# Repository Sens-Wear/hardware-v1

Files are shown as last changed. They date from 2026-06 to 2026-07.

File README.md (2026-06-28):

# SensWear Hardware

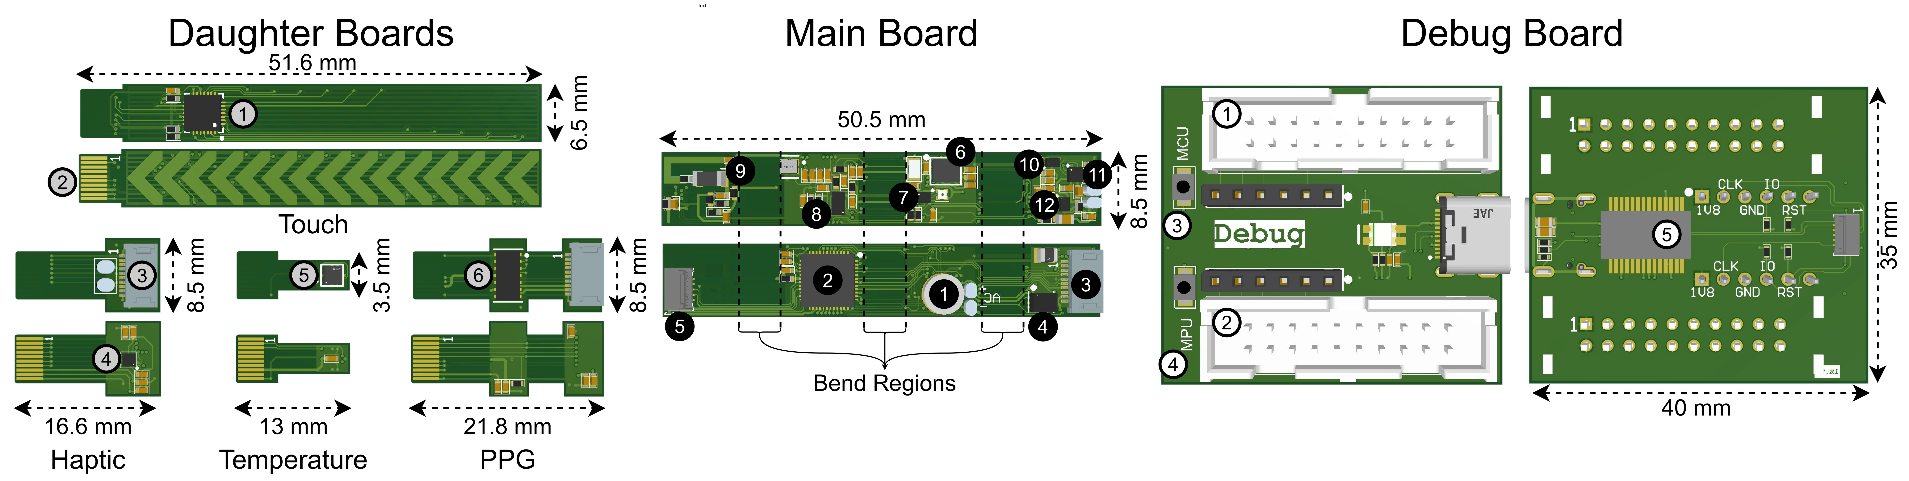
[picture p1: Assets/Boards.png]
SensWear hardware boards


SensWear is a modular wearable sensing platform. This repository contains the Altium Designer source files, reusable component libraries, PCB layouts, schematics, generated documentation, and manufacturing outputs for the SensWear V1R1 hardware.

The design is split into a main board and several function-specific boards so that each part of the system can be developed, reviewed, manufactured, and tested independently. A multi-board project is also included to support system-level integration.

## Repository structure

```text
hardware-v1/
├── Assets/                       Shared project assets
├── Components/                   Reusable schematic and PCB component libraries
│   └── IBIS/                     Signal-integrity models
├── Resources/                    Supporting design resources
├── Templates/                    Altium document and project templates
├── SensWear-V1R1-Main/           Main controller/hub board
├── SensWear-V1R1-Debug/          Programming, debug, SWD, and UART-to-USB board
├── SensWear-V1R1-Haptic/         Haptic-feedback board
├── SensWear-V1R1-PPG/            Optical PPG sensing board
├── SensWear-V1R1-Temperature/    Temperature-sensing board
├── SensWear-V1R1-Touch/          Touch-sensing board
├── SensWear-V1R1-Panel/          Sensor-panel PCB and panel manufacturing project
├── SensWear_V1R1/                Altium multi-board integration project
└── SensWear_V1R1.DsnWrk          Top-level Altium design workspace
```

Most board folders follow this layout:

```text
SensWear-V1R1-<Board>/
├── *.PrjPcb                      Altium PCB project
├── Schematics/ or Schematic/     Schematic source documents
├── PCB/                          PCB layout source document
├── Output/                       Generated review and manufacturing files
│   └── Manufacturing/
│       ├── Assembly/             BOM, pick-and-place, and assembly drawings
│       └── Fabrication/          Gerber and NC drill files
├── Project Outputs for .../      Altium-generated reports and validation results
└── History/                      Local Altium document history, where present
```

The Altium source files are the authoritative design sources. Files under `Output/` and `Project Outputs for .../` are generated artifacts and may need to be regenerated after a source change.

## Board documentation and generated outputs

The following links point to the primary generated documents for each hardware section. The `Manufacturing` links provide access to the available BOMs, pick-and-place files, assembly drawings, Gerbers, drill files, and packaged fabrication outputs.

| Section | Purpose | Design documentation | Manufacturing documentation and outputs |
|---|---|---|---|
| Main board | Central hub containing the main processing, power, memory, and system interfaces | [Schematics PDF](SensWear-V1R1-Main/Output/SensWear_V1R1_Schematics.PDF) | [Manufacturing PDF](SensWear-V1R1-Main/Output/Manufacturing/Assembly/SensWear_MainBoard_Manufacturing.PDF) · [All manufacturing outputs](SensWear-V1R1-Main/Output/Manufacturing/) |
| Debug board | Programming and debugging interfaces, including SWD and UART-to-USB | [Documentation PDF](SensWear-V1R1-Debug/Output/SensWear_Debug_Documentation.PDF) · [Schematics PDF](SensWear-V1R1-Debug/Output/SensWear_Debug_Schematics.PDF) | [Manufacturing PDF](SensWear-V1R1-Debug/Output/Manufacturing/Assembly/SensWear_Debug_Manufacturing.PDF) · [All manufacturing outputs](SensWear-V1R1-Debug/Output/Manufacturing/) |
| Haptic board | Haptic-feedback circuitry | [Documentation PDF](SensWear-V1R1-Haptic/Output/SensWear_Haptic_Documentation.PDF) | No standalone manufacturing PDF is currently included · [All manufacturing outputs](SensWear-V1R1-Haptic/Output/Manufacturing/) |
| PPG board | Optical photoplethysmography sensing | [Documentation PDF](SensWear-V1R1-PPG/Output/SensWear_PPG_Documentation.PDF) | [Manufacturing PDF](SensWear-V1R1-PPG/Output/Manufacturing/Assembly/SensWear_PPG_Manufacturing.PDF) · [All manufacturing outputs](SensWear-V1R1-PPG/Output/Manufacturing/) |
| Temperature board | Temperature sensing | [Documentation PDF](SensWear-V1R1-Temperature/Output/SensWear_Temperature_Documentation.PDF) | [Manufacturing PDF](SensWear-V1R1-Temperature/Output/Manufacturing/Assembly/SensWear_Temperature_Manufacturing.PDF) · [All manufacturing outputs](SensWear-V1R1-Temperature/Output/Manufacturing/) |
| Touch board | Touch sensing and user-input interface | [Documentation PDF](SensWear-V1R1-Touch/Output/SensWear_Touch_Documentation.PDF) | [Manufacturing PDF](SensWear-V1R1-Touch/Output/Manufacturing/Assembly/Mate2D_v2_Touch_Manufacturing.PDF) · [All manufacturing outputs](SensWear-V1R1-Touch/Output/Manufacturing/) |
| Sensor panel | Sensor-panel PCB and panel-level manufacturing design | No standalone design PDF is currently included | [Manufacturing PDF](SensWear-V1R1-Panel/Output/Manufacturing/Assembly/SensWear_Panel_Manufacturing.PDF) · [All manufacturing outputs](SensWear-V1R1-Panel/Output/Manufacturing/) |

## Opening and reviewing the design

1. Install a compatible version of Altium Designer.
2. Open `SensWear_V1R1.DsnWrk` to load the top-level workspace.
3. Open the relevant board's `.PrjPcb` file to edit or compile that board independently.
4. Use the PDFs linked above for design review when Altium Designer is not available.
5. Before manufacturing, compile the project, run electrical and design-rule checks, and regenerate the relevant output jobs.

## Manufacturing notes

- Treat generated manufacturing files as revision-specific snapshots. Confirm that they match the intended source revision before placing an order.
- Review the BOM for component availability, approved substitutions, package compatibility, and supplier-specific part numbers.
- Verify board stack-up, controlled-impedance requirements, copper weight, finish, thickness, panelization, and assembly constraints with the selected manufacturer.
- Inspect Gerber and drill outputs in an independent viewer before release.
- Do not assume that the newest-looking dated archive is the approved release; use version control and release notes to identify the intended manufacturing package.

## Contributing

Contributions are welcome. Bug reports, design reviews, documentation improvements, component-library fixes, and hardware enhancements are all useful.

For design changes:

1. Create a focused branch for the change.
2. Update the Altium source documents rather than editing generated outputs alone.
3. Compile the affected project and run the appropriate ERC and DRC checks.
4. Regenerate documentation and manufacturing outputs affected by the change.
5. Clearly describe the motivation, affected boards, validation performed, and any manufacturing or firmware implications in the pull request.

Keep unrelated generated files, local history, editor state, and temporary files out of commits whenever possible.

## License

This project is licensed under the MIT License. You may use, copy, modify, merge, publish, distribute, sublicense, and sell copies of the project, including for commercial purposes, provided that the original copyright notice and MIT permission notice are included with copies or substantial portions of the project.

The software and design files are provided without warranty. Users are responsible for independently validating electrical safety, regulatory compliance, manufacturability, and fitness for their intended application.

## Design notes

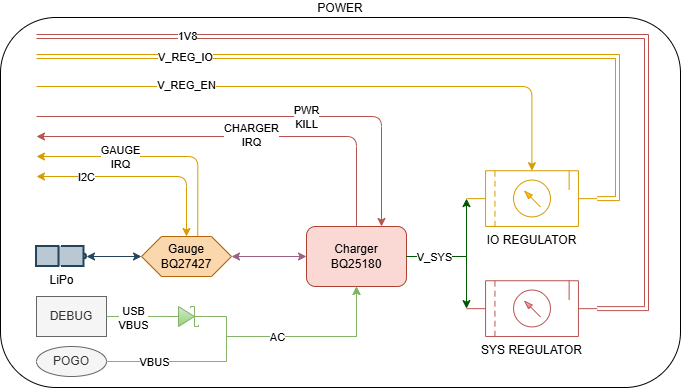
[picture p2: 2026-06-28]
Assets/SensWear-Hub-Power.drawio.png

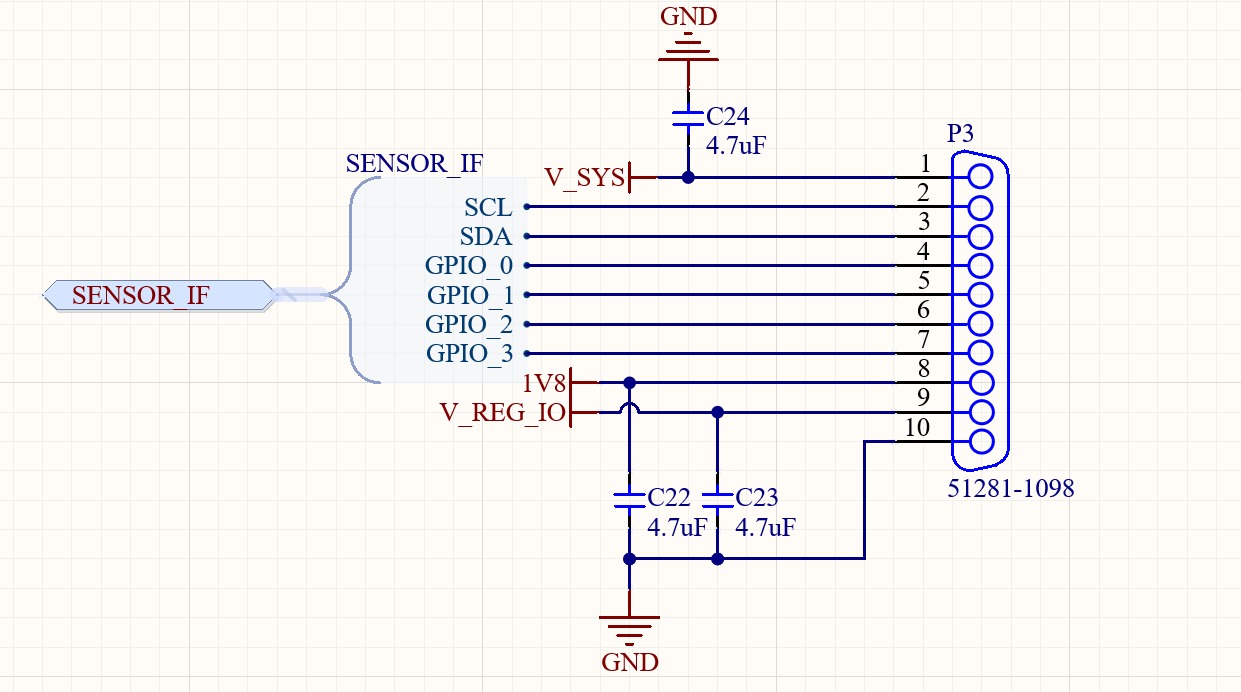
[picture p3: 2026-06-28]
Assets/DaughterBoardInterface.jpg

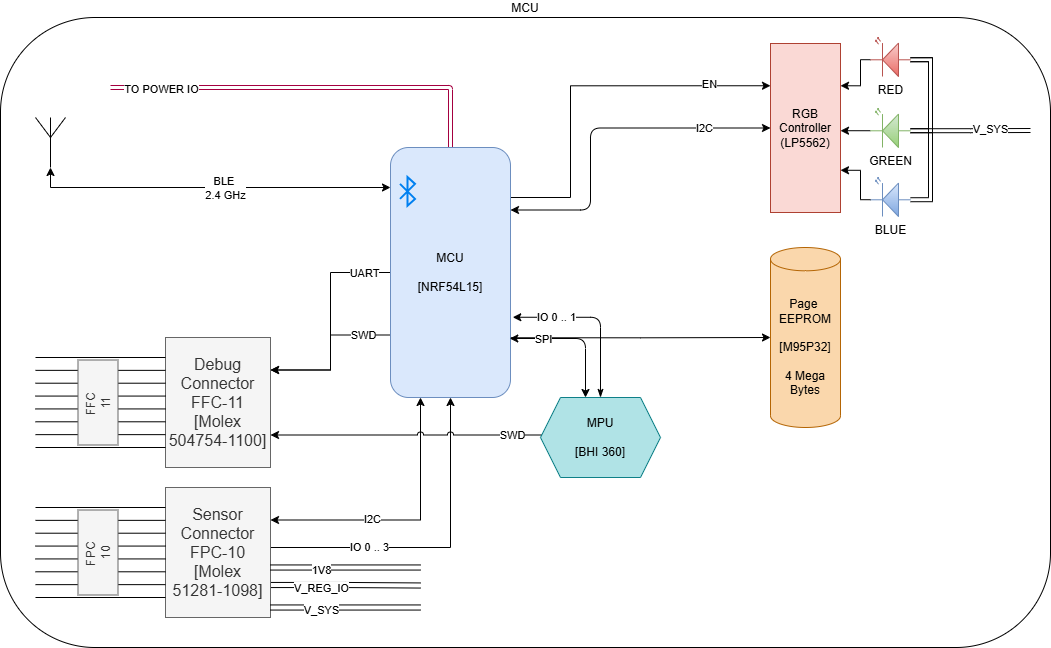
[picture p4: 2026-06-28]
Assets/SensWear-Hub-MCU.drawio.png

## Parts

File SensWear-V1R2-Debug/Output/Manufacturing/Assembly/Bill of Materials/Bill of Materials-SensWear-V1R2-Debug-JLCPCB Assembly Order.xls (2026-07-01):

JLCPCB BOM Tool - BOM Matching
BOM name：Bill of Materials-SensWear-V1R2-Debug-JLCPCB Assembly Order.xlsx |  |  | Download Time：2026-07-01 23:04:09 |  |  |  | * Our matching results are updated in real-time, but stock and prices may change. If it's been over 24 hours, please re-match before placing your order.
PCB Assembled Qty：5 |  |  | Est. Total Price：138.0418
Your BOM |  |  |  |  | Matched Parts |  |  |  |  |  |  | Order Information
Top Designator | Bottom Designator | Comment | Footprint | JLCPCB Part # | Matches | Part # | Manufacturer | Footprint | Description | Category | Warning | JLCPCB Part # | Product link | Lib Type | Qty | Source | Total Price ($)
B50,B51,B52 |  |  | B3U-1000P |  | Select by Customer | B3U-1000P | Omron Electronics | SMD,3x2.5mm | -25℃~+70℃ 1.53N 1.6mm 12V 2.5mm 3mm 50mA Round Button SMD(SMT) Tab SPST Surface Mount,Vertical SMD,3x2.5mm Tactile Switches ROHS | Tactile Switches |  | C231329 | https://jlcpcb.com/partdetail/OmronElectronics-B3U1000P/C231329 | Extended | 62 | 62 JLCPCB | 8.4506
 | C51 | 4.7uF | CAPC1005X05N |  | Select by Customer | CL05A475MP5NRNC | Samsung Electro-Mechanics | 0402 | 10V 4.7uF X5R ±20% 0402 Multilayer Ceramic Capacitors MLCC - SMD/SMT ROHS | Multilayer Ceramic Capacitors MLCC - SMD/SMT |  | C23733 | https://jlcpcb.com/partdetail/24469-CL05A475MP5NRNC/C23733 | Basic | 30 | 30 JLCPCB | 0.888
 | C69,C70 | 15pF | CAPC1005X05N |  | Select by Customer | 0402CG150J500NT | FH (Guangdong Fenghua Advanced Tech) | 0402 | 15pF 50V C0G ±5% 0402 Multilayer Ceramic Capacitors MLCC - SMD/SMT ROHS | Multilayer Ceramic Capacitors MLCC - SMD/SMT |  | C1548 | https://jlcpcb.com/partdetail/1900-0402CG150J500NT/C1548 | Basic | 50 | 50 JLCPCB | 0.43
C55 | C52,C53,C54,C56,C57,C58,C59,C60,C61,C62,C63,C71,C72 | 0.1uF | CAPC1005X05N |  | Select by Customer | CL05B104KO5NNNC | Samsung Electro-Mechanics | 0402 | 100nF 16V X7R ±10% 0402 Multilayer Ceramic Capacitors MLCC - SMD/SMT ROHS | Multilayer Ceramic Capacitors MLCC - SMD/SMT | 1.The comment (CL05B104KO5NNNC) of this part does not match the one (0.1uF) provided in your BOM. Please confirm; | C1525 | https://jlcpcb.com/partdetail/1877-CL05B104KO5NNNC/C1525 | Basic | 300 | 300 JLCPCB | 0.69
C66 | C50,C64,C65,C67,C68 | 4.7uF | CAPC1610X05N |  | Select by Customer | CL10A475KP8NNNC | Samsung Electro-Mechanics | 0603 | 10V 4.7uF X5R ±10% 0603 Multilayer Ceramic Capacitors MLCC - SMD/SMT ROHS | Multilayer Ceramic Capacitors MLCC - SMD/SMT |  | C1705 | https://jlcpcb.com/partdetail/2057-CL10A475KP8NNNC/C1705 | Extended | 140 | 140 JLCPCB | 1.694
 | D50 |  | SODFL360X110-2N |  | Select by Customer | MBR140SFT1G | onsemi | SOD-123FL | -55℃~+125℃ 1 Independent 1A 30A 40V 500uA@40V 550mV@1A SOD-123FL Schottky Diodes ROHS | Schottky Diodes |  | C43381 | https://jlcpcb.com/partdetail/onsemi-MBR140SFT1G/C43381 | Extended | 20 | 20 JLCPCB | 3.078
D51,D52,D53 |  |  | LTST-C155KGJRKT |  | Select by Customer | LTST-C155KGJRKT | Lite-On | SMD-4P,3.2x2.7mm | -55℃~+85℃ 130° 20mA 2V、2V 35mcd、45mcd 571nm、631nm 574nm、639nm 75mW Discrete Diode Red, Yellow Green Water Clear SMD-4P,3.2x2.7mm LED Indication - Discrete ROHS | LED Indication - Discrete |  | C115448 | https://jlcpcb.com/partdetail/LiteOn-LTSTC155KGJRKT/C115448 | Extended | 64 | 64 JLCPCB | 4.1216
 | FB50 |  | MURA-BLM15-CHIP-2_V |  | Select by Customer | BLM15AG601SN1D | Murata Electronics | 0402 | 1 300mA 520mΩ 600Ω@100MHz ±25% 0402 Ferrite Beads ROHS | Ferrite Beads |  | C76884 | https://jlcpcb.com/partdetail/MurataElectronics-BLM15AG601SN1D/C76884 | Extended | 32 | 32 My Parts | 0
 | L50 | 2.2uH | FP-DFE201612C-MFG |  | Select by Customer | DFE201612E-2R2M=P2 | Murata Electronics | 0806 | 1.8A 116mΩ 2.2uH 2.4A ±20% 0806 Power Inductors ROHS | Power Inductors |  | C337893 | https://jlcpcb.com/partdetail/MurataElectronics-DFE201612E_2R2MP2/C337893 | Extended | 22 | 22 JLCPCB | 4.4902
L51 |  | 3.3µH | AOTAB201610S3R3101T |  | Select by Customer | AOTA-B201610S3R3-101-T | Abracon LLC | 0806 | 0806 Power Inductors ROHS | Power Inductors |  | C42411119 | https://jlcpcb.com/partdetail/AbraconLLC-AOTA_B201610S3R3_101T/C42411119 | Extended | 20 | 20 JLCPCB | 5.606
 | R54 | 1M | RESC1005X04N |  | Select by Customer | 0402WGF1004TCE | UNI-ROYAL(Uniroyal Elec) | 0402 | -55℃~+155℃ 1MΩ 50V 62.5mW Thick Film Resistor ±1% ±100ppm/℃ 0402 Chip Resistor - Surface Mount ROHS | Chip Resistor - Surface Mount | 1.The comment (0402WGF1004TCE) of this part does not match the one (1M) provided in your BOM. Please confirm; | C26083 | https://jlcpcb.com/partdetail/26826-0402WGF1004TCE/C26083 | Basic | 30 | 30 My Parts | 0
 | R55 | 267kΩ | RESC1005X04N |  | Select by Customer | RTT022673FTH | RALEC | 0402 | -55℃~+155℃ 267kΩ 50V 62.5mW Thick Film Resistor ±1% ±100ppm/℃ 0402 Chip Resistor - Surface Mount ROHS | Chip Resistor - Surface Mount |  | C159057 | https://jlcpcb.com/partdetail/RALEC-RTT022673FTH/C159057 | Extended | 30 | 30 JLCPCB | 0.021
 | R56,R58 | 27R | ResThickFilm040227Ohm1%0.1W±100ppm/°CMoldedSMDPunchedCarrierT/R |  | Select by Customer | 0402WGJ0270TCE | UNI-ROYAL(Uniroyal Elec) | 0402 | -55℃~+155℃ 27Ω 50V 62.5mW Thick Film Resistor ±100ppm/℃ ±5% 0402 Chip Resistor - Surface Mount ROHS | Chip Resistor - Surface Mount | 1.The comment (0402WGJ0270TCE) of this part does not match the one (ResThickFilm040227Ohm1%0.1W±100ppm/°CMoldedSMDPunchedCarrierT/R) provided in your BOM. Please confirm; | C25156 | https://jlcpcb.com/partdetail/25899-0402WGJ0270TCE/C25156 | Extended | 50 | 50 JLCPCB | 0.04
 | R57 | 33R | RESC1005X04N |  | Select by Customer | 0402WGF330JTCE | UNI-ROYAL(Uniroyal Elec) | 0402 | -55℃~+155℃ 33Ω 50V 62.5mW Thick Film Resistor ±1% ±100ppm/℃ 0402 Chip Resistor - Surface Mount ROHS | Chip Resistor - Surface Mount | 1.The comment (0402WGF330JTCE) of this part does not match the one (33R) provided in your BOM. Please confirm; | C25105 | https://jlcpcb.com/partdetail/25848-0402WGF330JTCE/C25105 | Basic | 30 | 30 JLCPCB | 0.138
 | R59,R62,R63,R74,R75,R76,R77,R78,R79 | 1k | RESC1005X04N |  | Select by Customer | 0402WGF1001TCE | UNI-ROYAL(Uniroyal Elec) | 0402 | -55℃~+155℃ 1kΩ 50V 62.5mW Thick Film Resistor ±1% ±100ppm/℃ 0402 Chip Resistor - Surface Mount ROHS | Chip Resistor - Surface Mount | 1.The comment (0402WGF1001TCE) of this part does not match the one (1k) provided in your BOM. Please confirm; | C11702 | https://jlcpcb.com/partdetail/12256-0402WGF1001TCE/C11702 | Basic | 190 | 190 JLCPCB | 0.798
 | R60,R61 | 5.1k | RESC1005X04N |  | Select by Customer | 0402WGF5101TCE | UNI-ROYAL(Uniroyal Elec) | 0402 | -55℃~+155℃ 5.1kΩ 50V 62.5mW Thick Film Resistor ±1% ±100ppm/℃ 0402 Chip Resistor - Surface Mount ROHS | Chip Resistor - Surface Mount | 1.The comment (0402WGF5101TCE) of this part does not match the one (5.1k) provided in your BOM. Please confirm; | C25905 | https://jlcpcb.com/partdetail/26648-0402WGF5101TCE/C25905 | Basic | 50 | 50 JLCPCB | 0.05
 | R64,R65,R66,R67 | 100R | RESC1005X04N |  | Select by Customer | 0402WGF1000TCE | UNI-ROYAL(Uniroyal Elec) | 0402 | -55℃~+155℃ 100Ω 50V 62.5mW Thick Film Resistor ±1% ±100ppm/℃ 0402 Chip Resistor - Surface Mount ROHS | Chip Resistor - Surface Mount | 1.The comment (0402WGF1000TCE) of this part does not match the one (100R) provided in your BOM. Please confirm; | C25076 | https://jlcpcb.com/partdetail/25819-0402WGF1000TCE/C25076 | Basic | 90 | 90 JLCPCB | 0.135
 | R68,R69,R70,R71,R72,R73 | 620R | RESC1005X04N |  | Select by Customer | 0402WGF6200TCE | UNI-ROYAL(Uniroyal Elec) | 0402 | -55℃~+155℃ 50V 62.5mW 620Ω Thick Film Resistor ±1% ±100ppm/℃ 0402 Chip Resistor - Surface Mount ROHS | Chip Resistor - Surface Mount |  | C4961 | https://jlcpcb.com/partdetail/5369-0402WGF6200TCE/C4961 | Extended | 130 | 130 JLCPCB | 0.143
SWD_RP50,UART_RP50 |  |  | JST-SM03B-SRSS-TB_V |  | Select by Customer | HC-1.0-3PWT | HCTL | SMD,P=1mm,卧贴 | -25℃~+85℃ 1 1A 1mm 1x3P 3 3.2mm 3P 5.05mm 5.3mm 50V Auxiliary Solder Pin LCP Phosphor bronze SH Surface Mount, Right Angle Tin UL94V-0 SMD,P=1mm,卧贴 Wire To Board Connector ROHS | Wire To Board Connector | 1.There may be multiple types of parts, but one type of part has been matched. Please check.; | C2845362 | https://jlcpcb.com/partdetail/HCTL-HC_1_03PWT/C2845362 | Extended | 44 | 44 JLCPCB | 3.7224
 | T50,T51,T52 |  | FP-DQK0006B-MFG |  | Select by Customer | CSD87502Q2 | Texas Instruments | WSON-6(2x2) | -55℃~+150℃ 2 N-Channel 2.3W 2V 30V 32.4mΩ@10V 353pF 5A 6nC@10V WSON-6(2x2) MOSFETs ROHS | MOSFETs |  | C701752 | https://jlcpcb.com/partdetail/TexasInstruments-CSD87502Q2/C701752 | Extended | 60 | 60 JLCPCB | 16.716
 | U50 |  | BGA6C50P2X3_96X146X62 |  | Select by Customer | FPF1320UCX | onsemi | WLCSP-6(1x1.7) | -40℃~+85℃ 1.5A 1.5V~5.5V 2 50mΩ Active High Load Switch WLCSP-6(1x1.7) Power Distribution Switches ROHS | AC-DC Controllers And Regulators |  | C457734 | https://jlcpcb.com/partdetail/onsemi-FPF1320UCX/C457734 | Extended | 20 | 20 JLCPCB | 14.024
 | U51 |  | BGA6C40P2X3_97X147X50 |  | Select by Customer | TPS62840YBGR | Texas Instruments | DSBGA-6(1x1.5) | -40℃~+125℃@(TJ) 1 1.8MHz 1.8V~3.3V 1.8V~6.5V 750mA Adjustable Buck Buck Built-in Yes DSBGA-6(1x1.5) DC-DC Converters ROHS | DC-DC Converters |  | C2071139 | https://jlcpcb.com/partdetail/TexasInstruments-TPS62840YBGR/C2071139 | Extended | 20 | 20 My Parts | 0
 | U52 |  | SON50P100X50-6N |  | Select by Customer | PRTR5V0U2F,115 | Nexperia | XSON-6(1x1.5) | -40℃~+85℃ 100nA 1pF 2 5.5V 6V IEC 61000-4-2 TVS Unidirectional XSON-6(1x1.5) ESD and Surge Protection (TVS/ESD) ROHS | ESD And Surge Protection (TVS/ESD) |  | C478118 | https://jlcpcb.com/partdetail/Nexperia-PRTR5V0U2F115/C478118 | Extended | 20 | 20 JLCPCB | 2.208
U53 |  |  | QFN40P700X700X90_HS-61N |  | Select by Customer | RP2354A | Raspberry Pi | QFN-60(7x7) | Power-on reset (POR)、Undervoltage detection (BOR/LVD/LVR/LVI)、Watchdog reset、Built-in general-purpose timer、Integrated LDO、Calendar function、True random number generator (TRNG)、Hardware ECC check、Independent watchdog (IWDG) QFN-60(7x7) Microcontrollers (MCU/MPU/SOC) ROHS | Global Sourcing Parts |  | C41378174 | https://jlcpcb.com/partdetail/RaspberryPi-RP2354A/C41378174 | Extended | 20 | 20 JLCPCB | 26.084
 | U54,U55 |  | YZP0005ADAD |  | Select by Customer | SN74LVC1G17YZPR | Texas Instruments | DSBGA-5 | -40℃~+85℃ 1 1 1.65V~5.5V 10uA 32mA 32mA 4.6ns@3.3V,15pF 74LVC Schmitt trigger Unidirectional DSBGA-5 Buffers, Drivers, Receivers, Transceivers ROHS | Buffers, Drivers, Receivers, Transceivers |  | C2862333 | https://jlcpcb.com/partdetail/TexasInstruments-SN74LVC1G17YZPR/C2862333 | Extended | 40 | 40 JLCPCB | 13.64
USB50 |  |  | JAE-DX07S024JJ3R1300-MFG |  | Select by Customer | DX07S024JJ3R1300 | JAE Electronics | SMD | -30℃~+80℃ 1 24P 250mA、1.25A 48V Black Female Surface Mount, Right Angle Type-C USB 3.2 SMD USB Connectors ROHS | USB Connectors |  | C134111 | https://jlcpcb.com/partdetail/JAEElectronics-DX07S024JJ3R1300/C134111 | Extended | 20 | 20 JLCPCB | 25.022
 | X50 |  | DFN165P250X80-4N |  | Select by Customer | ABM8-272-T3 | Abracon LLC | SMD3225-4P | -40℃~+85℃ 10pF 12MHz 50Ω Crystal Oscillator ±30ppm ±30ppm SMD3225-4P Crystals ROHS | Crystals |  | C20625731 | https://jlcpcb.com/partdetail/AbraconLLC-ABM8_272T3/C20625731 | Extended | 20 | 20 JLCPCB | 5.852
 | P50 |  | 5047541100__3 |  | No matches | No Part Selected

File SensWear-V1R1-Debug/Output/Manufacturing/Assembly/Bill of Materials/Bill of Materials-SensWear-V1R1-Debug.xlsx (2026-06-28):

Manufacturer | Manufacturer Part Number | Designator | Quantity | Value | Comment | Description | Supplier 1 | Supplier Part Number 1
Molex | 504754-1100 | P80 | 1 |  | 504754-1100 | Conn FFC/FPC Connector SKT 11 POS 0.3mm Solder RA SMD Easy-On™ T/R | Mouser | 538-504754-1100
AMP - TE CONNECTIVITY | 5103308-5 | JLINK80A, JLINK80B | 2 |  | 5103308-5 | Header; Pin; Vertical; Copper Alloy; Thermoplastic; 20; 0.100 x 0.100 in.; 1 A | Digi-Key | A33165-ND
Molex | 0150310411 | CABLE | 1 |  | 0150310411 | 0.30mm Pitch Premo-Flex FPC Jumper with Notches, Same Side Contacts (Type A), 102.00mm Cable Length, Gold (Au) Plating, 11 Circuits | Mouser | 538-15031-0411
Omron Electronics Inc-EMC Div | B3U-1000P | RST80A, RST80B | 2 |  | B3U-1000P | SWITCH TACTILE SPST-NO 0.05A 12V | Digi-Key | SW1020DKR-ND
Murata | BLM15AG601SN1D | FB80 | 1 |  | BLM15AG601SN1D | FERRITE BEAD 600 OHM 0402 1LN | Digi-Key | 490-1006-1-ND
Samsung | CL10A475KP8NNNC | C82, C83 | 2 |  | 4.7uF | Cap Ceramic 4.7uF 10V X5R 10% Pad SMD 0603 85C T/R | Digi-Key | 1276-1044-1-ND
JAE Electronics | DX07S024JJ3R1300 | USB80 | 1 |  | DX07S024JJ3R1300 | Cut Tape - Usb Type C Receptacle Mid Mnt Dual R | Mouser | 656-DX07S024JJ3R1300
Panasonic Electronic Components | ERJ-2RKF1000X | R82, R83 | 2 | 100 R | 100 R | RES SMD 100 OHM 1% 1/10W 0402 | Digi-Key | P100LDKR-ND
Panasonic Electronic Components | ERJ-2RKF1002X | R80A, R80B, R81A, R81B | 4 | 10 k | 10 k | RES SMD 10K OHM 1% 1/10W 0402 | Digi-Key | P10.0KLDKR-ND
Panasonic | ERJ-2RKF5101X | R84, R85 | 2 | 5.1 k | 5.1 k | RES SMD 5.1K OHM 1% 1/10W 0402 | Mouser | 667-ERJ-2RKF5101X
FTDI, Future Technology Devices International Ltd | FT232RL-REEL | U80 | 1 |  | FT232RL | IC USB FS SERIAL UART 28-SSOP | Digikey | 768-1007-6-ND
Murata Electronics | GRM155R61C104KA88D | C80, C81, C84 | 3 | 0.1 uF | 0.1 uF | CAP CER 0.1UF 16V X5R 0402 | Mouser | 81-GRM155R61C104KA8D
Vishay Lite-On | LTST-C155KGJRKT | D80 | 1 |  | LTST-C155KGJRKT | LED GREEN/RED CLEAR CHIP SMD | Digi-Key | 160-1409-1-ND
ON Semiconductor | MBR140SFT1G | D81 | 1 |  | MBR140SFT1G | DIODE SCHOTTKY 40V 1A SOD123L | Digi-Key | MBR140SFT1GOSDKR-ND
Samtec | SSQ-106-23-F-S | SWD80A, SWD80B | 2 |  | SSQ-106-23-F-S | Headers & Wire Housings Tiger Buy Socket Strip with Square Tails, 0.100 Pitch | Digikey | SSQ-106-23-F-S-ND

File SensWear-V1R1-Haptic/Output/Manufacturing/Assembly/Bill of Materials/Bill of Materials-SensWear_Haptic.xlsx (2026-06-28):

Manufacturer | Manufacturer Part Number | Designator | Quantity | Value | Comment | Description | Supplier 1 | Supplier Part Number 1
 |  | CONN40 | 1 |  | NC
Molex | 51281-1098 | P40 | 1 |  | 51281-1098 | FFC/FPC Connector, Surface Mount, Right-Angle, Non-ZIF, Dual Contact Style | Mouser | 538-51281-1098
Texas Instruments | DRV2605LYZFR | U40 | 1 |  | DRV2605LYZFR | Haptic driver for ERM/LRA with 2-V operation, waveform library & auto-resonance tracking 9-DSBGA -40 to 85 | Mouser | 595-DRV2605LYZFR
Jinlong Machinery & Electronics, Inc. | G0832012 | M40 | 1 |  | G0832012 | VIBRATION MOTOR 1.8V | Digi-Key | 1670-1034-ND
Murata Electronics North America | GRM155R61A105KE15D | C41 | 1 | 1 uF | 1 uF | CAP CER 1UF 10V X5R 0402 | Digi-Key | 490-3890-6-ND
Murata Electronics North America | GRM155R61A474KE15D | C42 | 1 | 0.47 uF | 0.47 uF | CAP CER 0.47UF 10V X5R 0402 | Digi-Key | 490-3264-6-ND
Murata | GRM155R61A475MEAAD | C40, C43, C44 | 3 | 4.7uF | 4.7uF | Multilayer Ceramic Capacitor, 4.7 uF, 10 V, ± 20%, X5R, 0402 [1005 Metric] | Mouser | 81-GRM155R61A475MEAD

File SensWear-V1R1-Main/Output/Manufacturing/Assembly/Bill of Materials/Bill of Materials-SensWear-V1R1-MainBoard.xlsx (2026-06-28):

Manufacturer | Manufacturer Part Number | Designator | Quantity | Value | Comment | Description | Supplier 1 | Supplier Part Number 1
 |  | C38, C39 | 2 |  | NC
Johanson | 2450AT18E0100E | ANT1 | 1 |  | 2450AT18E0100E | 7 Inch Reel / Mini 2.45Ghz Chip Antenna | Mouser | 609-2450AT18E0100E
Molex | 51281-1098 | P3 | 1 |  | 51281-1098 | FFC/FPC Connector, Surface Mount, Right-Angle, Non-ZIF, Dual Contact Style | Mouser | 538-51281-1098
Molex | 504754-1100 | P2 | 1 |  | 504754-1100 | Conn FFC/FPC Connector SKT 11 POS 0.3mm Solder RA SMD Easy-On™ T/R | Mouser | 538-504754-1100
Abracon | ABM11W-32.0000MHZ-8-B1U-T3 | X1 | 1 |  | 32 MHz | CRYSTAL 32.0000MHZ 8PF SMD, 2x1.6mm, RoHS | Mouser | 815-11W32-8B1UT
Abracon Corporation | ABS06-32.768KHZ-1-T | X2 | 1 |  | 32.768kHz | CRYSTAL 32.768 KHZ 12.5 PF SMD | Digi-Key | 535-10248-6-ND
Bosch Tools | BHI360 | U8 | 1 |  | BHI360 | Programmable smart sensor combining accelerometer, gyroscope and fusion software | Digikey | 828-BHI360DKR-ND
Murata | BLM15AG121SN1D | FB1 | 1 |  | BLM15AG121SN1D | Ferrite Beads Multi-Layer 120Ohm 25% 100MHz 550mA 190mOhm DCR 0402 Paper T/R | Mouser | 81-BLM15AG121SN1D
Texas Instruments | BQ25180YBGR | U4 | 1 |  | BQ25180YBGR | 1-A Li-ion I²C programmable charger with regulated power path in WCSP package 8-DSBGA -40 to 85 | Mouser | 595-BQ25180YBGR
Texas Instruments | BQ27427YZFR | U7 | 1 |  | BQ27427YZFR | Single-cell battery fuel gauge with pre-programmed chemistry and integrated sense resistor 9-DSBGA -40 to 85 | Mouser | 595-BQ27427YZFR
Samsung | CL05A106MP5NUNC | C6, C8, C14 | 3 | 10uF | 10uF | Multilayer Ceramic Capacitor, 10 uF, 10 V, ± 20%, X5R, 0402 [1005 Metric] | Mouser | 187-CL05A106MP5NUNC
Samsung | CL10A476MQ8QRNC | C15 | 1 | 47uF | 47uF | CL10 Series 0603 47 uF 6.3 V ±20% Tolerance X5R Multilayer Ceramic Capacitor | Digikey | 1276-CL10A476MQ8QRNCCT-ND
Murata | DFE201612E-2R2M=P2 | L1 | 1 | 2.2 uH | 2.2 uH | Inductor Power Shielded Wirewound 2.2uH 20% 1MHz Metal 1.8A 0.116Ohm DCR 0806 T/R | Mouser | 81-DFE201612E-2R2MP2
Panasonic Electronic Components | ERJ-2GE0R00X | R13, R14 | 2 | 0R0 | 0R0 | RES SMD 0.0OHM JUMPER 1/10W 0402 | Digi-Key | P0.0JDKR-ND
Panasonic Electronic Components | ERJ-2RKF1002X | R19 | 1 | 10 k | 10 k | RES SMD 10K OHM 1% 1/10W 0402 | Digi-Key | P10.0KLDKR-ND
Panasonic Electronic Components | ERJ-2RKF1003X | R4 | 1 | 100 k | 100 k | RES SMD 100K OHM 1% 1/10W 0402 | Digi-Key | P100KLDKR-ND
Panasonic Electronic Components | ERJ-2RKF1004X | R1, R3, R6, R7, R8, R9 | 6 | 1 M | 1 M | RES SMD 1M OHM 1% 1/10W 0402 | Digi-Key | P1.00MLDKR-ND
Panasonic Electronic Components | ERJ-2RKF1501X | R2, R15, R16 | 3 | 1.5 k | 1.5 k | RES SMD 1.5K OHM 1% 1/10W 0402 | Digi-Key | P1.50KLDKR-ND
Murata | GJM1555C1H1R5BB01D | C33 | 1 | 1.5 pF | 1.5 pF | Multilayer Ceramic Capacitor, 1.5 pF, 50 V, ï¿½ 0.1pF, C0G (NP0), 0402 [1005 Metric] | Mouser | 81-GJM1555C1H1R5BB1D
Murata | GJM1555C1H2R0WB01D | C36 | 1 | 2 pF | 2 pF | 0402 2 pF 50V ±0.05 pF Tolerance C0G SMT Multilayer Ceramic Capacitor | Mouser | 81-GJM1555C1H2R0WB1D
Murata | GJM1555C1HR30WB01D | C37 | 1 | 0.3pF | 0.3pF | 0402 0.3 pF 50V ±0.05 pF Tolerance C0G SMT Multilayer Ceramic Capacitor | Mouser | 81-GJM1555C1HR30WB1D
Murata Electronics North America | GRM155R61A105KE15D | C12, C17 | 2 | 1 uF | 1 uF | CAP CER 1UF 10V X5R 0402 | Digi-Key | 490-3890-6-ND
Murata Electronics North America | GRM155R61A225KE95D | C16, C28, C30 | 3 | 2.2 uF | 2.2 uF | CAP CER 2.2UF 10V X5R 0402 | Digi-Key | 490-10451-6-ND
Murata | GRM155R61A475MEAAD | C7, C10, C22, C23, C24 | 5 | 4.7uF | 4.7uF | Multilayer Ceramic Capacitor, 4.7 uF, 10 V, ± 20%, X5R, 0402 [1005 Metric] | Mouser | 81-GRM155R61A475MEAD
Murata Electronics | GRM155R61C104KA88D | C1, C2, C5, C9, C11, C18, C19, C26, C27, C29 | 10 | 0.1 uF | 0.1 uF | CAP CER 0.1UF 16V X5R 0402 | Mouser | 81-GRM155R61C104KA8D
Murata | GRM155R61C224KA12D | C21 | 1 | 220nF | 220nF | CAP CER 0.22UF 16V X5R 0402 | Mouser | 81-GRM155R61C224KA2D
Murata Electronics North America | GRM155R71H103KA88D | C25, C31, C32 | 3 | 10 nF | 10 nF | CAP CER 10000PF 50V X7R 0402 | Digi-Key | 490-4516-6-ND
Murata | GRM1555C1H8R0BA01D | C34, C35 | 2 | 8pF | 8pF | Multilayer Ceramic Capacitors MLCC - SMD/SMT 0402 8.0pF 50volts C0G +/-0.05pF | Mouser | 81-GRM1555C1H8R0BA1D
Texas Instruments | LP5562TME/NOPB | U5 | 1 |  | LP5562TME | IC LED DRIVER LINEAR DIM 25.5MA | Digi-Key | 296-39060-6-ND
Murata | LQG15WH2N7B02D | L4 | 1 | 2.7 nH | 2.7 nH | Inductor Chip 2.7nH 0.1nH Tolerance 2-Pin 0402 Paper T/R | Mouser | 81-LQG15WH2N7B02D
Murata | LQG15WH3N5B02D | L5, L6 | 2 | 3.5 nH | 3.5 nH | Inductor Chip 3.5nH 0.1nH Tolerance 2-Pin 0402 Paper T/R | Mouser | 81-LQG15WH3N5B02D
Murata | LQM18FN4R7M00D | L3 | 1 | 4.7uH | 4.7uH | Inductor Power Chip Shielded Multi-Layer 4.7uH 20% 1MHz Ferrite 0.08A 0.78Ohm DCR 0603 T/R | Mouser | 81-LQM18FN4R7M00D
STMicroelectronics | M95P32-IXCST/EF | U2 | 1 |  | M95P32-IXCST/EF | M95P32-I Series 32 Mb (4 M x 8) 80 MHz SPI EEPROM Memory IC - WLCSP-8 | Mouser | 511-M95P32-IXCST/EF
Nordic Semiconductor | NRF54L15-QFAA-R | U1 | 1 |  | NRF54L15-QF | nRF54L15 SoC with Arm Cortex-M33 processor
XTPogoPin | RM-1238-B02-41 | P1 | 1 |  | RM-1238-B02-41 | RM-1238-B02-41 by www.xtpogopin.com
Lumex | SML-LX0404SIUPGUSB | LED1 | 1 |  | SML-LX0404SIUPGUSB | LED Low-Power Tri-Color Blue/Green/Red 465nm/518nm/632nm 2.7V/2.75V/1.95V 4-Pin SMD T/R
Texas Instruments | TPS62840YBGR | U3 | 1 |  | TPS62840YBGR | Conv DC-DC 1.8V to 6.5V Synchronous Step Down Single-Out 1.8V to 3.3V 0.75A 6-Pin DSBGA T/R | Mouser | 595-TPS62840YBGR
Texas Instruments | TPSM831021SIUR | U6 | 1 |  | TPSM831021SIUR | 1.5A output current, buck-boost MicroSiP™ power module with integrated inductor with I²C 8-uSiP -40 to 125 | Mouser | 595-TPSM831021SIUR

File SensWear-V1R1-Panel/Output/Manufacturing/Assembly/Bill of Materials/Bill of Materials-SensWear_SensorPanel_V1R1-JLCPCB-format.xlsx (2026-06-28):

Comment | Designator | Footprint | JLCPCB Part #
0.1uF | C60 | 0402 | CL05B104KO5NNNC
MultilayerCeramicCapacitor,10uF,10V,±20%,X5R,0402[1005Metric] | C51,C52 | 0402 | CGA0402X5R106M6R3GT
4.7uF | C40,C43,C44,C50,C53,C54 | 0402 | C1005X5R0J475MTJ00E
1uF | C41 | 0402 | CL05A105KA5NQNC
0.47uF | C42,C70 | 0402 | CL05A474KP5NNNC
51281-1098 | P40,P50 | SMD,P=0.5mm,卧贴 | 512811098
1.5k | R50,R70,R71,R72 | 0402 | 0402WGF1501TCE
DRV2605LYZFR | U40 | DSBGA-9 | DRV2605LYZFR
MAX30101EFD+T | U50 | OLGA-14(3.3x5.6) | MAX30101EFD+T
MAX30208CLB+T | U60 | LGA-10(2x2) | MAX30208CLB+T
MTCH6102-I/MV | U70 | UQFN-28-EP(4x4) | MTCH6102-I/MV
G0832012 | M40 | - | VG0832012
NC | CONN40
NC | CONN50
NC | CONN60
NC | CONN70,TOUCH

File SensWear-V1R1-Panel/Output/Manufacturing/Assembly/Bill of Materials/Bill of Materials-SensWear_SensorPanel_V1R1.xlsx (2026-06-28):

Manufacturer | Manufacturer Part Number | Designator | Quantity | Value | Comment | Description | Supplier 1 | Supplier Part Number 1
Murata Electronics | GRM155R61C104KA88D | C60 | 1 | 0.1 uF | 0.1 uF | CAP CER 0.1UF 16V X5R 0402 | Mouser | 81-GRM155R61C104KA8D
Murata Electronics North America | GRM155R61A474KE15D | C42 | 1 | 0.47 uF | 0.47 uF | CAP CER 0.47UF 10V X5R 0402 | Digi-Key | 490-3264-6-ND
Murata Electronics North America | GRM155R61A474KE15D | C70 | 1 | 0.47 uF | 0.47 uF | CAP CER 0.47UF 10V X5R 0402 | Digi-Key | 490-3264-6-ND
Murata Electronics North America | GRM155R61A105KE15D | C41 | 1 | 1 uF | 1 uF | CAP CER 1UF 10V X5R 0402 | Digi-Key | 490-3890-6-ND
Panasonic Electronic Components | ERJ-2RKF1501X | R50 | 1 | 1.5 k | 1.5 k | RES SMD 1.5K OHM 1% 1/10W 0402 | Digi-Key | P1.50KLDKR-ND
Panasonic Electronic Components | ERJ-2RKF1501X | R70, R71, R72 | 3 | 1.5 k | 1.5 k | RES SMD 1.5K OHM 1% 1/10W 0402 | Digi-Key | P1.50KLDKR-ND
Samsung | CL05A106MP5NUNC | C51, C52 | 2 | 10uF | 10uF | Multilayer Ceramic Capacitor, 10 uF, 10 V, ± 20%, X5R, 0402 [1005 Metric] | Mouser | 187-CL05A106MP5NUNC
Murata | GRM155R61A475MEAAD | C40, C43, C44 | 3 | 4.7uF | 4.7uF | Multilayer Ceramic Capacitor, 4.7 uF, 10 V, ± 20%, X5R, 0402 [1005 Metric] | Mouser | 81-GRM155R61A475MEAD
Murata | GRM155R61A475MEAAD | C50, C53, C54 | 3 | 4.7uF | 4.7uF | Multilayer Ceramic Capacitor, 4.7 uF, 10 V, ± 20%, X5R, 0402 [1005 Metric] | Mouser | 81-GRM155R61A475MEAD
Molex | 51281-1098 | P40 | 1 |  | 51281-1098 | FFC/FPC Connector, Surface Mount, Right-Angle, Non-ZIF, Dual Contact Style | Mouser | 538-51281-1098
Molex | 51281-1098 | P50 | 1 |  | 51281-1098 | FFC/FPC Connector, Surface Mount, Right-Angle, Non-ZIF, Dual Contact Style | Mouser | 538-51281-1098
Texas Instruments | DRV2605LYZFR | U40 | 1 |  | DRV2605LYZFR | Haptic driver for ERM/LRA with 2-V operation, waveform library & auto-resonance tracking 9-DSBGA -40 to 85 | Mouser | 595-DRV2605LYZFR
Jinlong Machinery & Electronics, Inc. | G0832012 | M40 | 1 |  | G0832012 | VIBRATION MOTOR 1.8V | Digi-Key | 1670-1034-ND
Maxim | MAX30101EFD+T | U50 | 1 |  | MAX30101EFD+T | High-Sensitivity Pulse Oximeter and Heart-Rate Sensor for Fitness & Healthcare | Mouser | 700-MAX30101EFD+T
Maxim | MAX30208CLB+T | U60 | 1 |  | MAX30208CLB+T | I2C Digital Temperature Sensor Serial I2C 10-Pin Thin LGA T/R | Mouser | 700-MAX30208CLB+T
Microchip | MTCH6102-I/MV | U70 | 1 |  | MTCH6102-I/MV | Capacitive Touch Screen Automotive 28-Pin UQFN EP Tube | Digikey | MTCH6102-I/MV-ND
 |  | CONN40 | 1 |  | NC
 |  | CONN50 | 1 |  | NC
 |  | CONN60 | 1 |  | NC
 |  | CONN70, Touch | 2 |  | NC

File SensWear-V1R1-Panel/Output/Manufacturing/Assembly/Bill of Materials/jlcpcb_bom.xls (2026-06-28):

Comment | Designator | Footprint | JLCPCB Part #
MAX30101EFD+T | U50 | OLGA-14(3.3x5.6) | C2859066
1uF | C41 | 0402 | C52923
51281-1098 | P40,P50 | SMD,P=0.5mm,卧贴 | C6961899
0.47uF | C42,C70 | 0402 | C47339
MultilayerCeramicCapacitor,10uF,10V,±20%,X5R,0402[1005Metric] | C51,C52 | 0402 | C7472949
1.5k | R50,R70,R71,R72 | 0402 | C25867
DRV2605LDGSR | U40 | 10-VSSOP
MAX30208CLB+T | U60 | LGA-10(2x2) | C2874216
0.1uF | C60 | 0402 | C1525
MTCH6102-I/MV | U70 | UQFN-28-EP(4x4) | C637766
4.7uF | C40,C43,C44,C50,C53,C54 | 0402 | C23733

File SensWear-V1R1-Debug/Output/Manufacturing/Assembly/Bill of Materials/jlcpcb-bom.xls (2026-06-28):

Comment | Designator | Footprint | JLCPCB Part #
BLM15AG601SN1D | FB80 | BLM15AG601SN1D | C560060
FT232RL | U80 | FT232RL | C8690
DX07S024JJ3R1300 | USB80 | DX07S024JJ3R1300 | C134111
4.7uF | C82,C83 | 0402 | C1705
0.1uF | C80,C81,C84 | 0402 | C1525
10k | R80A,R80B,R81A,R81B | 0402 | C25531
SSQ-106-23-F-S | SWD80A,SWD80B | SSQ-106-23-F-S | C124380
100R | R82,R83 | 0402 | C25076
5103308-5 | JLINK80A,JLINK80B | 5103308-5 | C305958
LTST-C155KGJRKT | D80 | LTST-C155KGJRKT | C115448
B3U-1000P | RST80A,RST80B | B3U-1000P | C231329
5.1k | R84,R85 | 0402 | C25905
504754-1100 | P80 | 504754-1100 | C3168136
MBR140SFT1G | D81 | SOD123L

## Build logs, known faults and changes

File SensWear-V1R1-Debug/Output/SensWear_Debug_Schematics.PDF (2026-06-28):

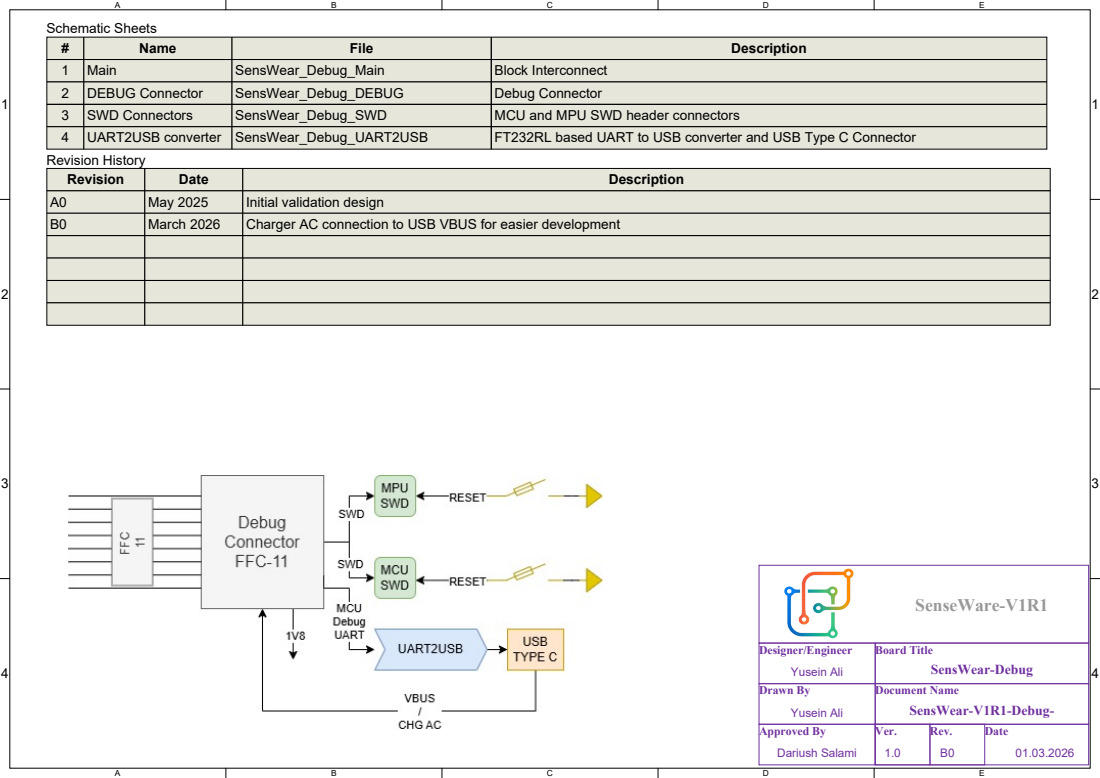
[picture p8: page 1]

Name | File | Description

1 | Main | SensWear_Debug_Main | Block Interconnect
2 | DEBUG Connector | SensWear_Debug_DEBUG | Debug Connector
3 | SWD Connectors | SensWear_Debug_SWD | MCU and MPU SWD header connectors
4 | UART2USB converter | SensWear_Debug_UART2USB | FT232RL based UART to USB converter and USB Type C Connector

Revision | Date | Description
A0 | May 2025 | Initial validation design
B0 | March 2026 | Charger AC connection to USB VBUS for easier development

Designer/Engineer Yusein Ali | Board Title SensWear-Debug

Drawn By Yusein Ali | Document Name SensWear-V1R1-Debug-

Approved By Dariush Salami | Ver. | Rev. B0 | Date 01.03.2026

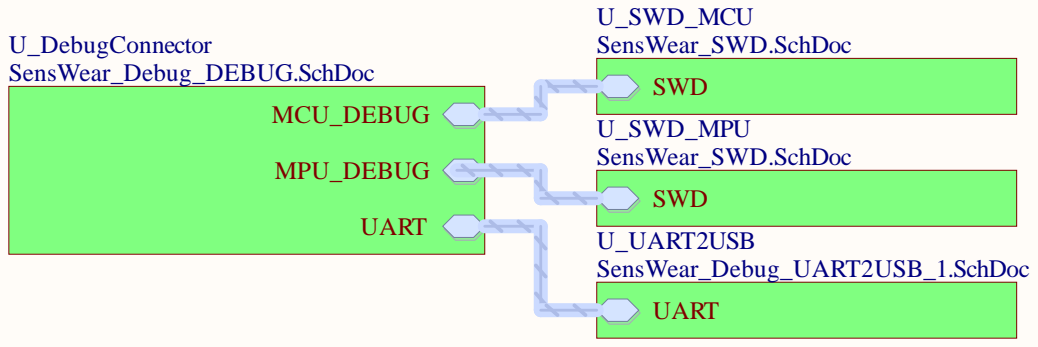
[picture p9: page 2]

SenseWare-V1R1

Designer/Engineer Designer/Engineer Yusein Ali Yusein Ali | Board Title Board Title SensWear-Debug SensWear-Debug

Drawn By Drawn By Yusein Ali Yusein Ali | Document Name Document Name SensWear_Debug_Main.SchDoc SensWear_Debug_Main.SchDoc

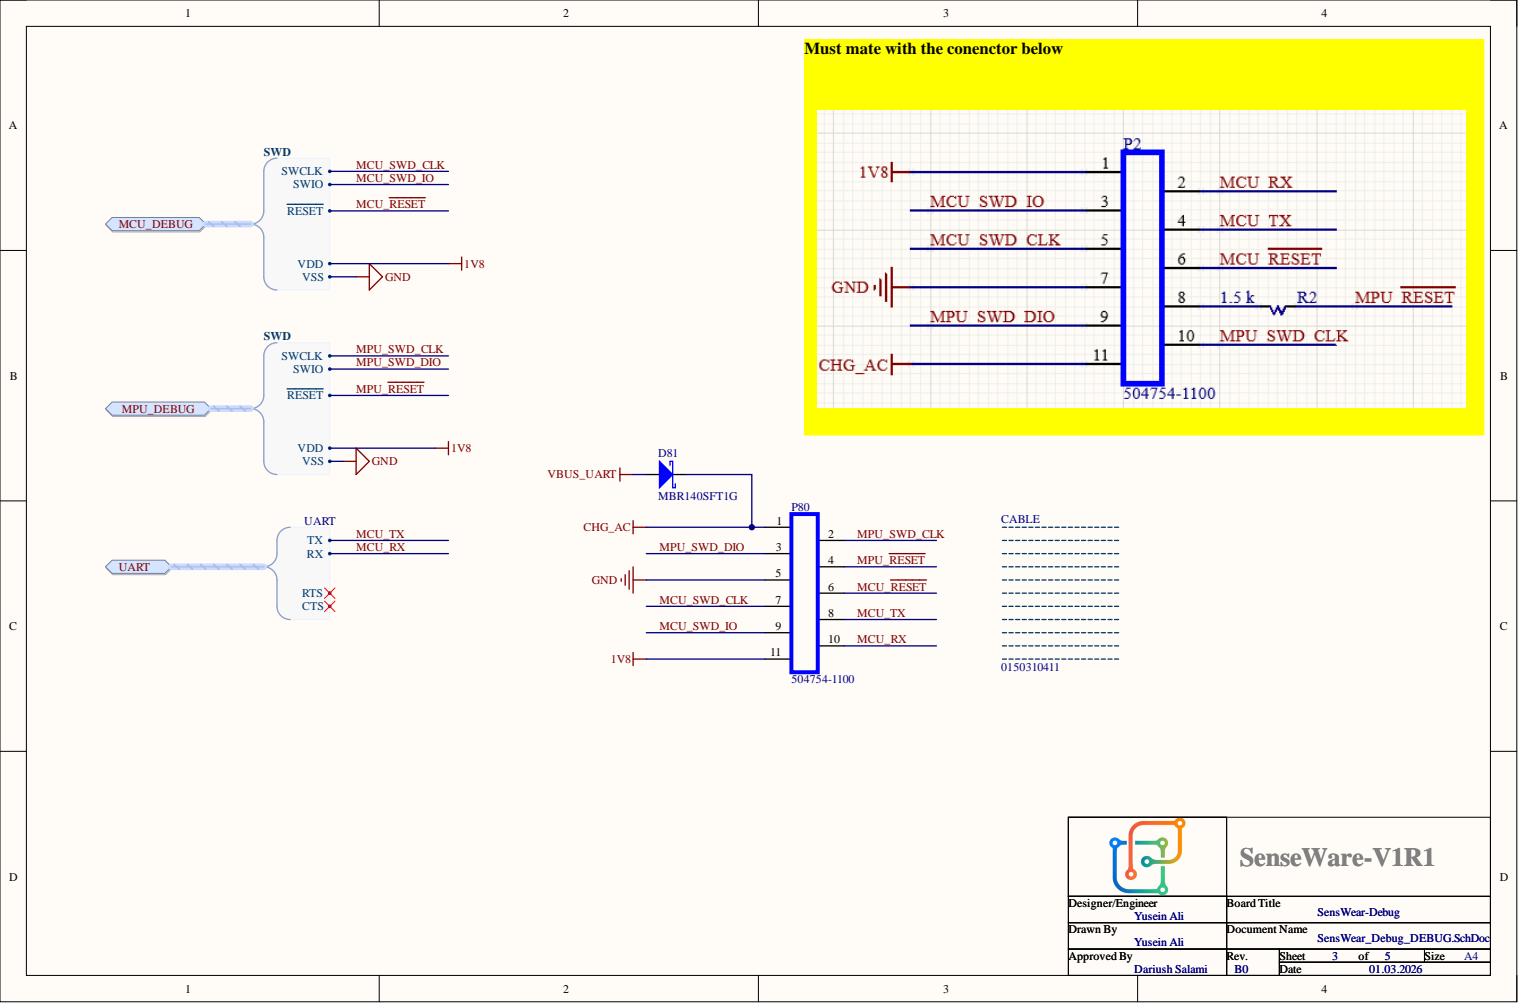
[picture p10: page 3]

Must mate with the conenctor below

SenseWare-V1R1

Designer/Engineer Designer/Engineer Yusein Ali Yusein Ali | Board Title Board Title SensWear-Debug SensWear-Debug

Drawn By Drawn By Yusein Ali Yusein Ali | Document Name Document Name SensWear_Debug_DEBUG.SchDoc SensWear_Debug_DEBUG.SchDoc

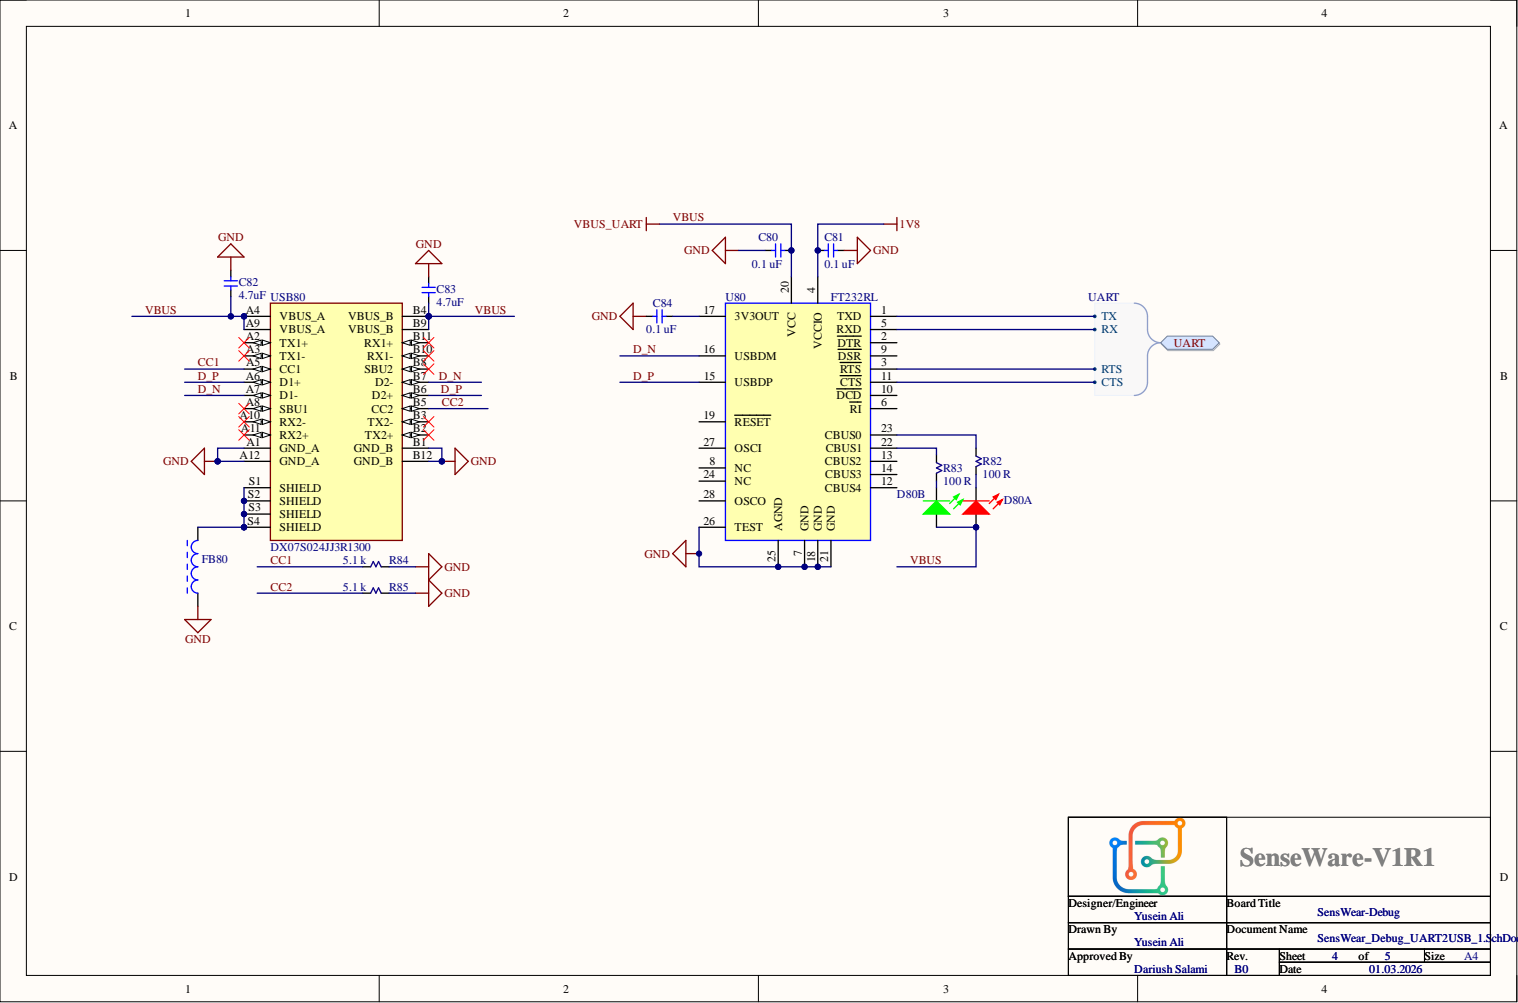
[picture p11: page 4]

SenseWare-V1 SenseWare-V1 R R 1 1

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

Draw Draw n By n By Yu Yu sei sei n n l l i i | ocumen ocumen t t Sen Sen s s Wear_ Wear_ Deb Deb u u g g _ _ U U RT RT USB_ USB_ . . S S

p p pro pro ved ved y y Dari Dari u u s s h Salam h Salam i i | Rev Rev . . | Shee Shee t t o o f f | Size

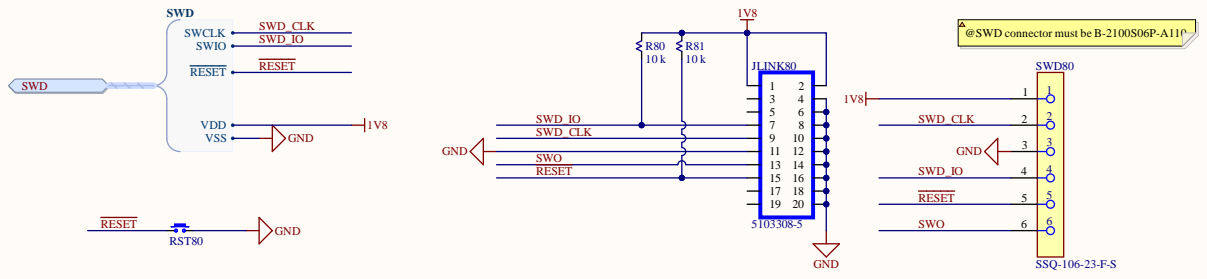
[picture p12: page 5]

SenseWare-V1 SenseWare-V1 R R 1 1

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

Draw Draw n By n By Yu Yu sei sei n n l l i i | ocumen ocumen t t Sen Sen s s Wear_SW Wear_SW D.Sc D.Sc h h o o c c

p p pro pro ved ved y y Dari Dari u u s s h Salam h Salam i i | Rev Rev . . | Shee Shee t t o o f f | Size

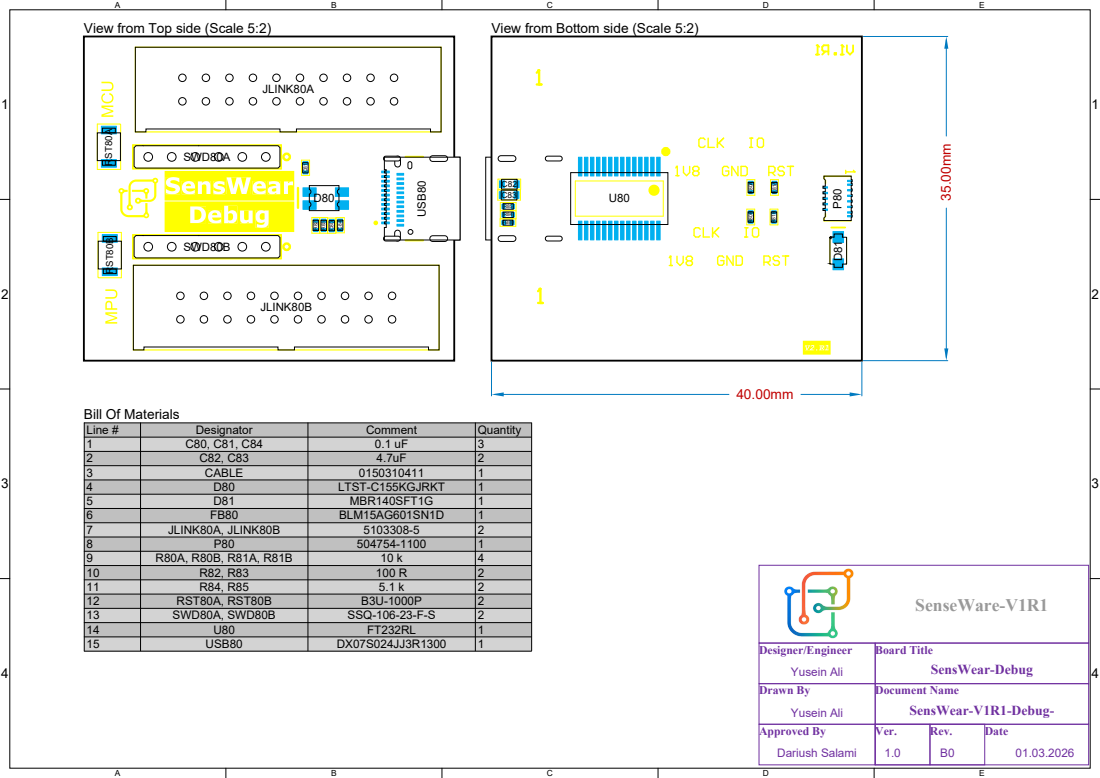
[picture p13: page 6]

View from Top side (Scale 5:2)

View from Bottom side (Scale 5:2)

Line # | Designator | Comment | Quantity
1 | C80, C81, C84 | 0.1 uF | 3
2 | C82, C83 | 4.7uF | 2
3 | CABLE | 0150310411 | 1
4 | D80 | LTST-C155KGJRKT | 1
5 | D81 | MBR140SFT1G | 1
6 | FB80 | BLM15AG601SN1D | 1
7 | JLINK80A, JLINK80B | 5103308-5 | 2
8 | P80 | 504754-1100 | 1
9 | R80A, R80B, R81A, R81B | 10 k | 4

11 | R84, R85 | 5.1 k | 2
12 | RST80A, RST80B | B3U-1000P | 2
13 | SWD80A, SWD80B | SSQ-106-23-F-S | 2
14 | U80 | FT232RL | 1
15 | USB80 | DX07S024JJ3R1300 | 1

Designer/Engineer Yusein Ali | Board Title SensWear-Debug

Drawn By Yusein Ali | Document Name SensWear-V1R1-Debug-

Approved By Dariush Salami | Ver. | B0 | Date 01.03.2026

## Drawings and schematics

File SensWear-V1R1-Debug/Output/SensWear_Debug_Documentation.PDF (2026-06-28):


Name | File | Description

1 | Main | SensWear_Debug_Main | Block Interconnect
2 | DEBUG Connector | SensWear_Debug_DEBUG | Debug Connector
3 | SWD Connectors | SensWear_Debug_SWD | MCU and MPU SWD header connectors
4 | UART2USB converter | SensWear_Debug_UART2USB | FT232RL based UART to USB converter and USB Type C Connector

Revision | Date | Description
A0 | May 2025 | Initial validation design
B0 | March 2026 | Charger AC connection to USB VBUS for easier development

Designer/Engineer Yusein Ali | Board Title SensWear-Debug

Drawn By Yusein Ali | Document Name SensWear-V1R1-Debug-

Approved By Dariush Salami | Ver. | Rev. B0 | Date 01.03.2026

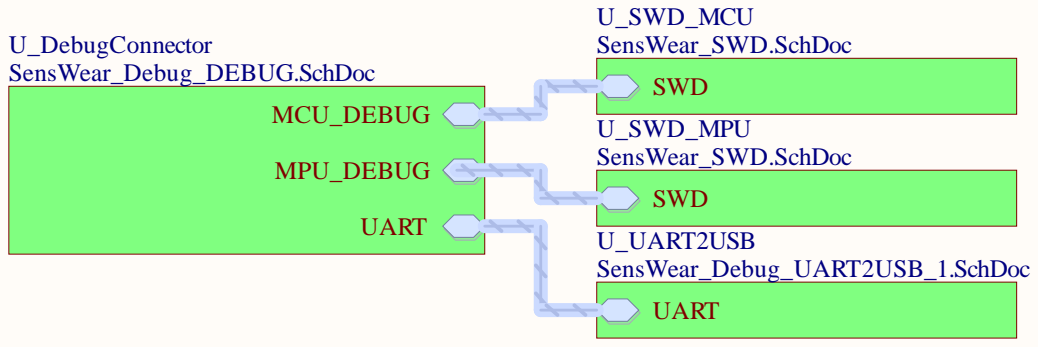
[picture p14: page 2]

SenseWare-V1R1

Designer/Engineer Designer/Engineer Yusein Ali Yusein Ali | Board Title Board Title SensWear-Debug SensWear-Debug

Drawn By Drawn By Yusein Ali Yusein Ali | Document Name Document Name SensWear_Debug_Main.SchDoc SensWear_Debug_Main.SchDoc

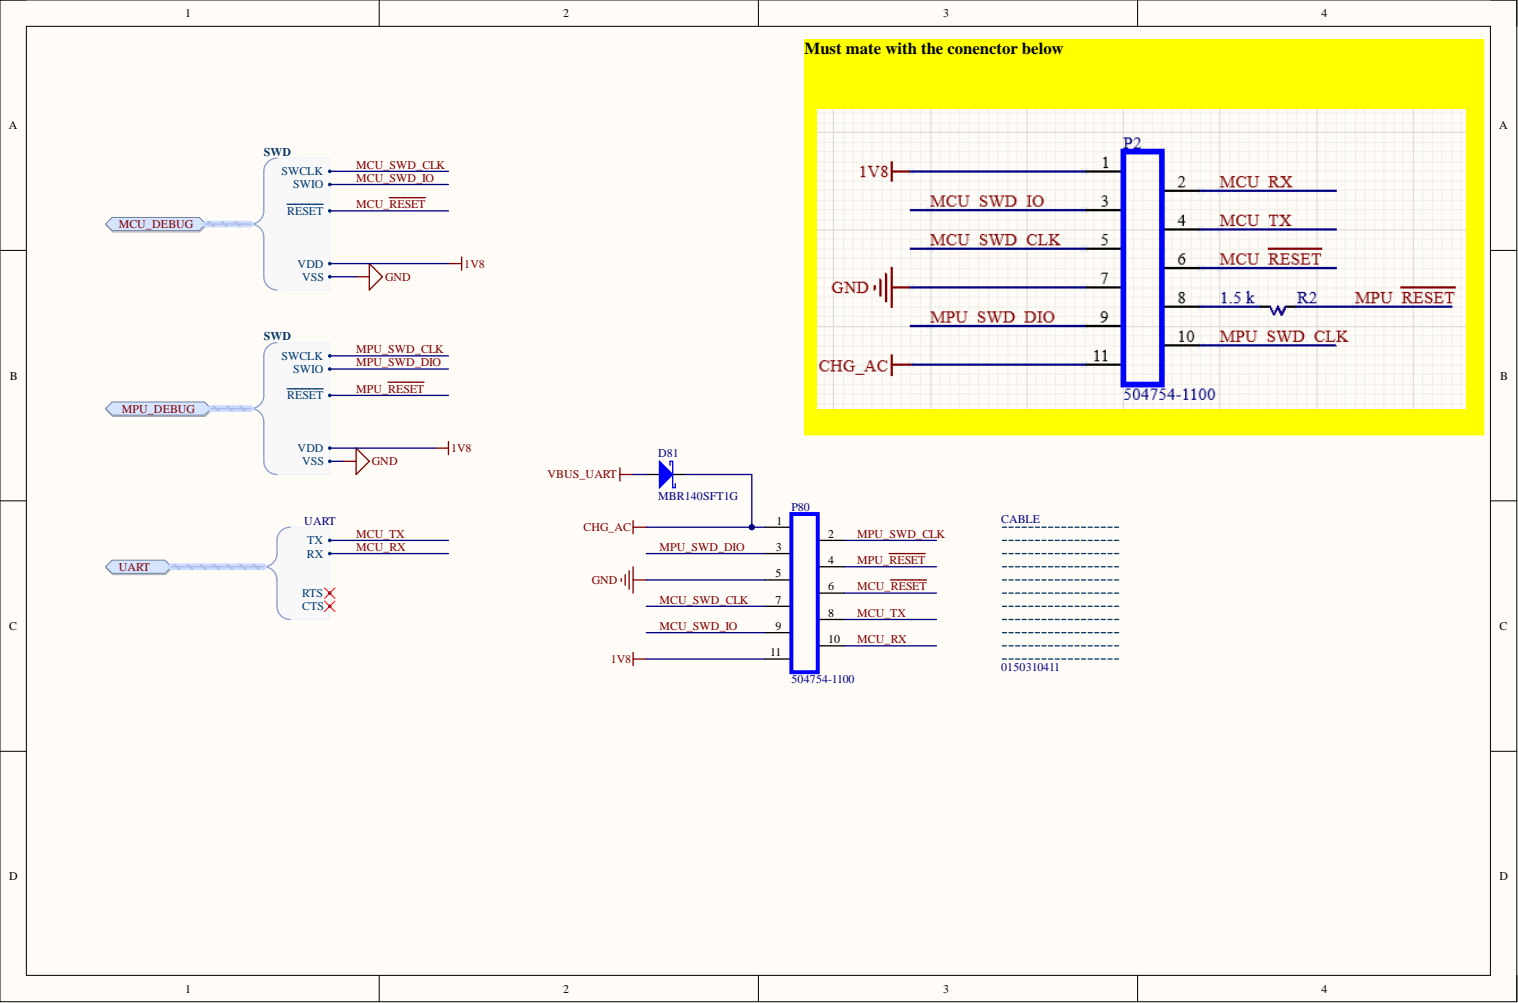
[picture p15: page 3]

Must mate with the conenctor below

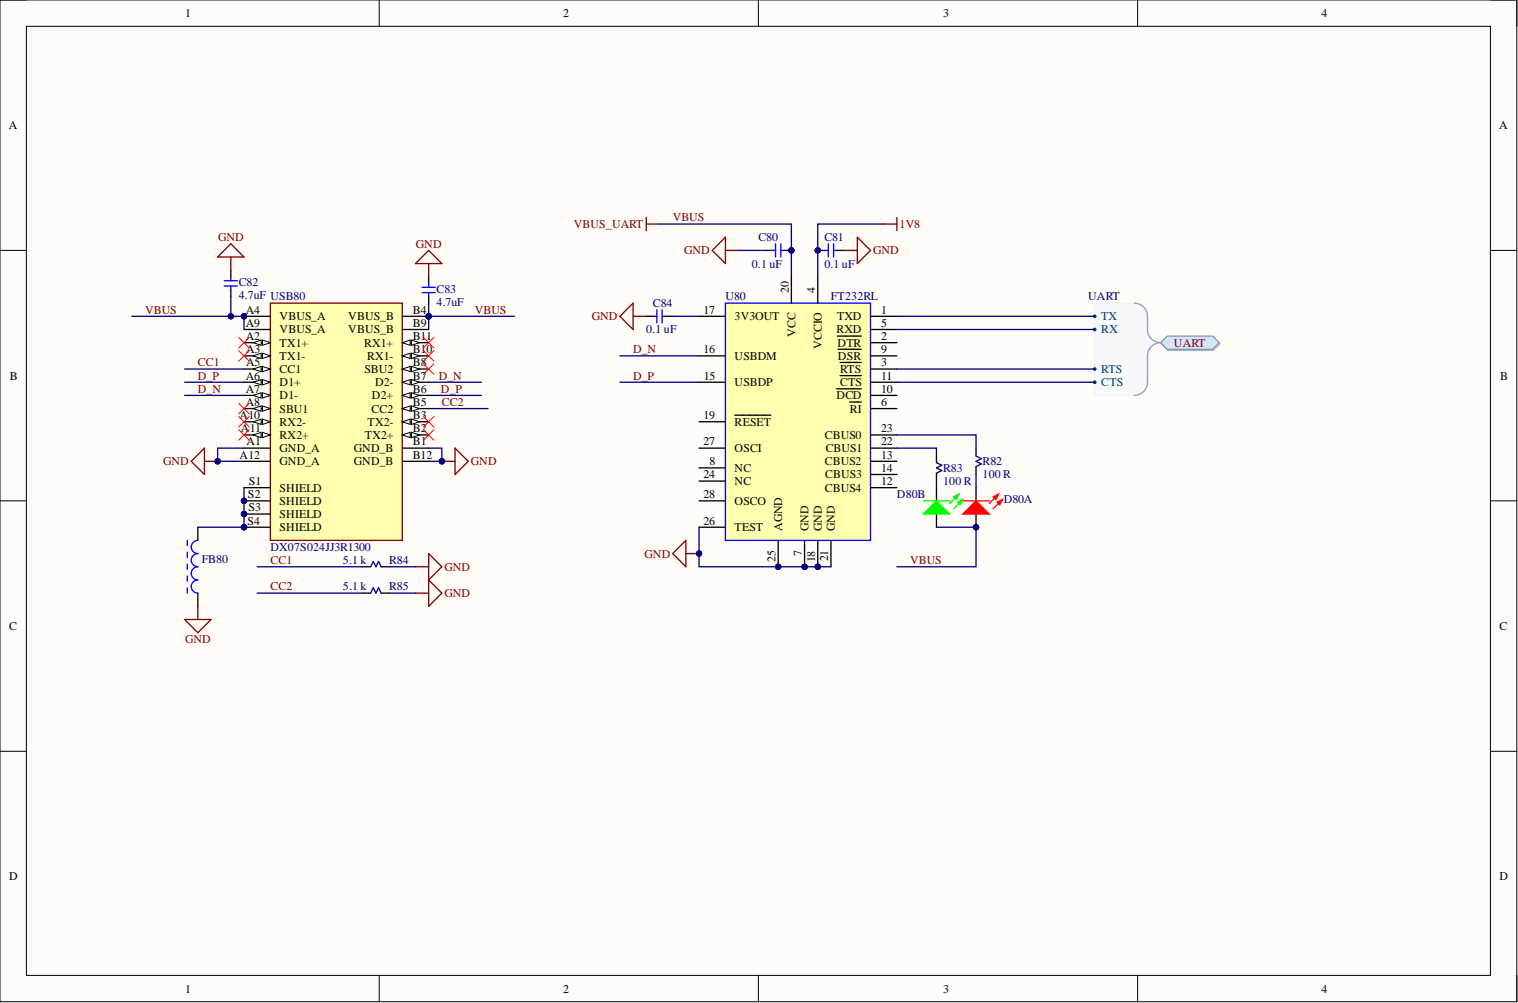
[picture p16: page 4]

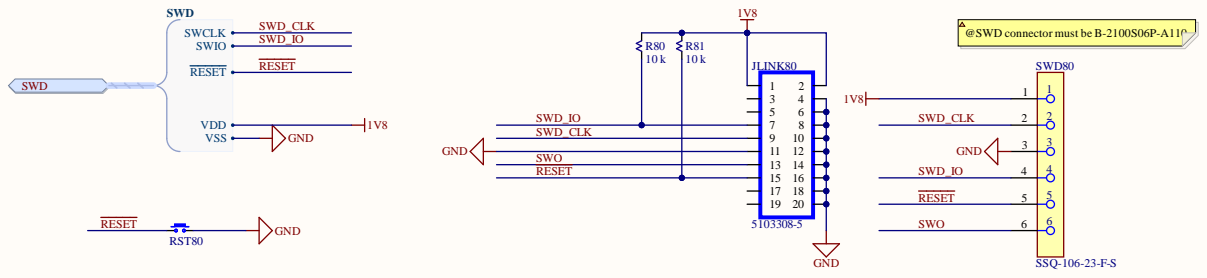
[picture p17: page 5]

SenseWare-V1 SenseWare-V1 R R 1 1

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

Draw Draw n By n By Yu Yu sei sei n n l l i i | ocumen ocumen t t Name Name Sen Sen s s Wear_SW Wear_SW D.Sc D.Sc h h o o c c

p p pro pro ved ved y y Dari Dari u u s s h Salam h Salam i i | Rev Rev . . B0 B0 | Shee Shee t t o o f f | Size

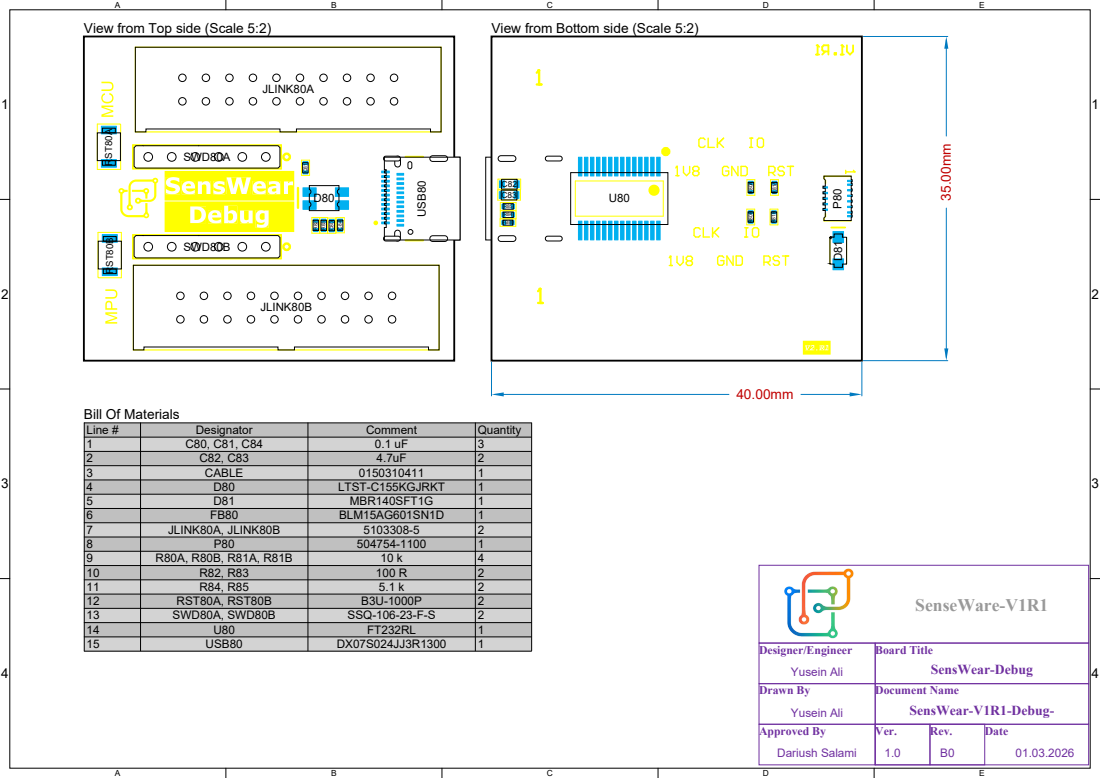
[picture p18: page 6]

View from Top side (Scale 5:2)

View from Bottom side (Scale 5:2)

Line # | Designator | Comment | Quantity
1 | C80, C81, C84 | 0.1 uF | 3
2 | C82, C83 | 4.7uF | 2
3 | CABLE | 0150310411 | 1
4 | D80 | LTST-C155KGJRKT | 1
5 | D81 | MBR140SFT1G | 1
6 | FB80 | BLM15AG601SN1D | 1
7 | JLINK80A, JLINK80B | 5103308-5 | 2
8 | P80 | 504754-1100 | 1
9 | R80A, R80B, R81A, R81B | 10 k | 4

11 | R84, R85 | 5.1 k | 2
12 | RST80A, RST80B | B3U-1000P | 2
13 | SWD80A, SWD80B | SSQ-106-23-F-S | 2
14 | U80 | FT232RL | 1
15 | USB80 | DX07S024JJ3R1300 | 1

Designer/Engineer Yusein Ali | Board Title SensWear-Debug

Drawn By Yusein Ali | Document Name SensWear-V1R1-Debug-

Approved By Dariush Salami | Ver. | B0 | Date 01.03.2026

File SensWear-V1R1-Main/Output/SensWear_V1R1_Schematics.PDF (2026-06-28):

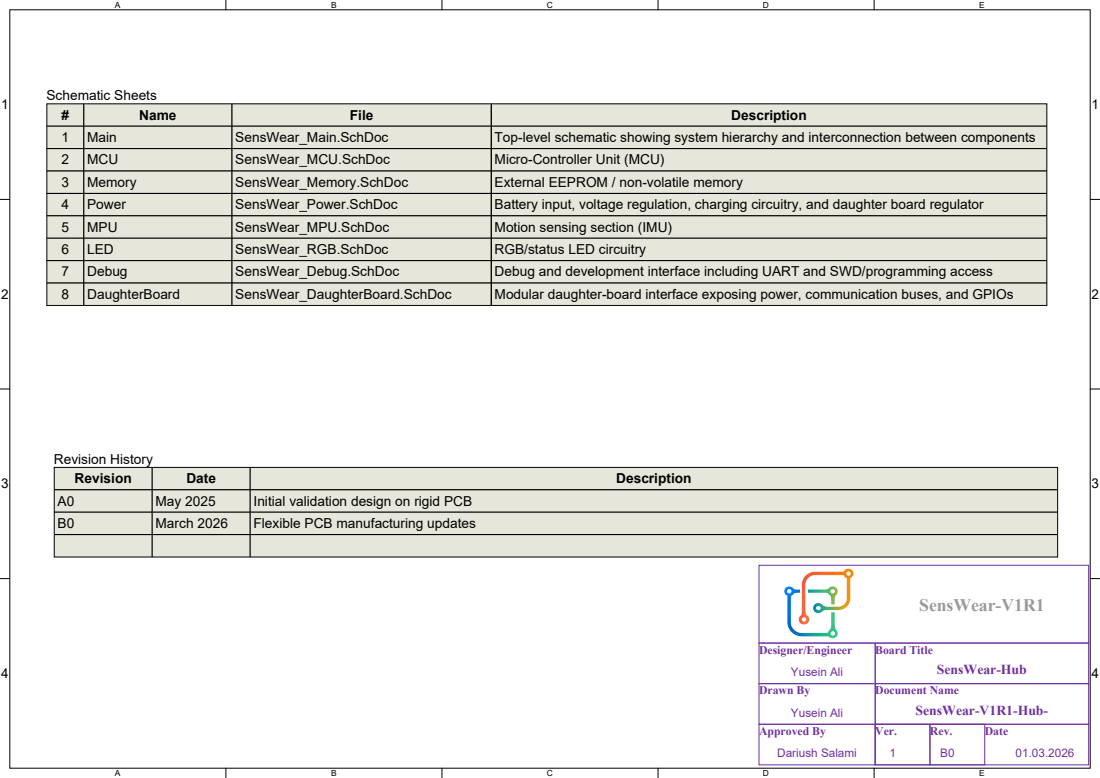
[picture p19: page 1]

# | Name | File | Description
1 | Main | SensWear_Main.SchDoc | Top-level schematic showing system hierarchy and interconnection between components
2 | MCU | SensWear_MCU.SchDoc | Micro-Controller Unit (MCU)
3 | Memory | SensWear_Memory.SchDoc | External EEPROM / non-volatile memory
4 | Power | SensWear_Power.SchDoc | Battery input, voltage regulation, charging circuitry, and daughter board regulator
5 | MPU | SensWear_MPU.SchDoc | Motion sensing section (IMU)
6 | LED | SensWear_RGB.SchDoc | RGB/status LED circuitry
7 | Debug | SensWear_Debug.SchDoc | Debug and development interface including UART and SWD/programming access
8 | DaughterBoard | SensWear_DaughterBoard.SchDoc | Modular daughter-board interface exposing power, communication buses, and GPIOs

Revision | Date | Description
A0 | May 2025 | Initial validation design on rigid PCB
B0 | March 2026 | Flexible PCB manufacturing updates

Designer/Engineer Yusein Ali | Board Title SensWear-Hub

Drawn By Yusein Ali | Document Name SensWear-V1R1-Hub-

Approved By Dariush Salami | Ver. | Rev. B0 | Date 01.03.2026

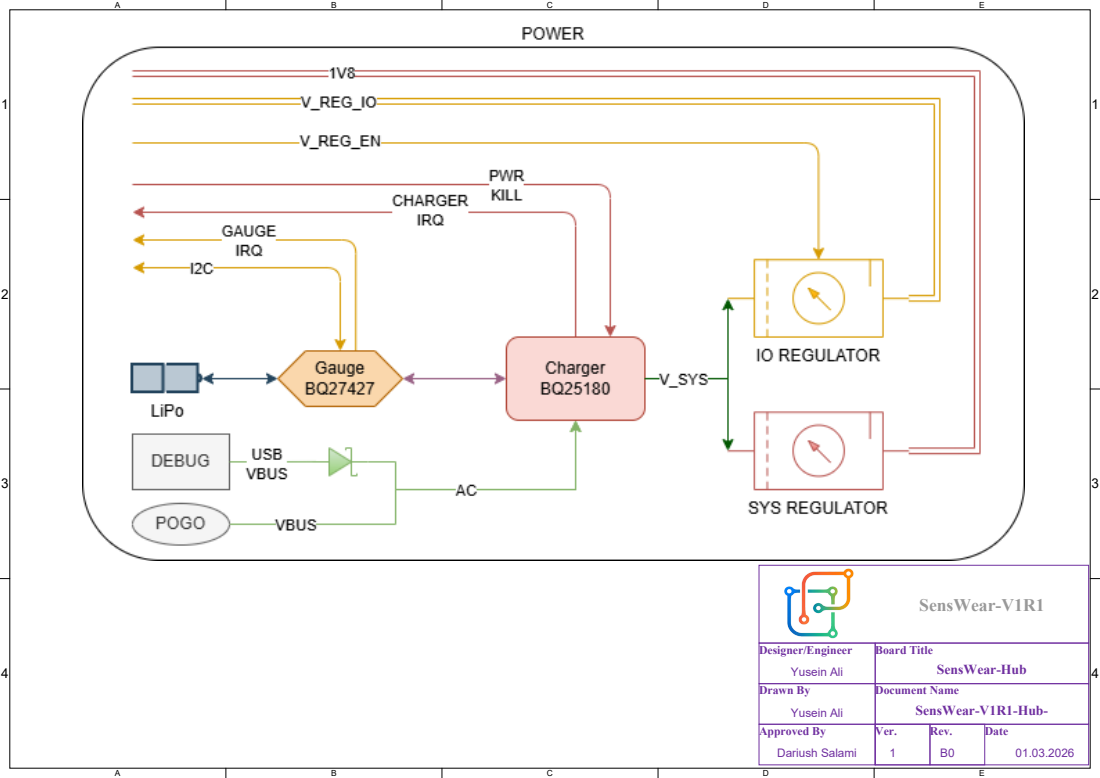
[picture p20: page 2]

Designer/Engineer Yusein Ali | Board Title SensWear-Hub

Drawn By Yusein Ali | Document Name SensWear-V1R1-Hub-

Approved By Dariush Salami | Ver. | B0 | Date 01.03.2026

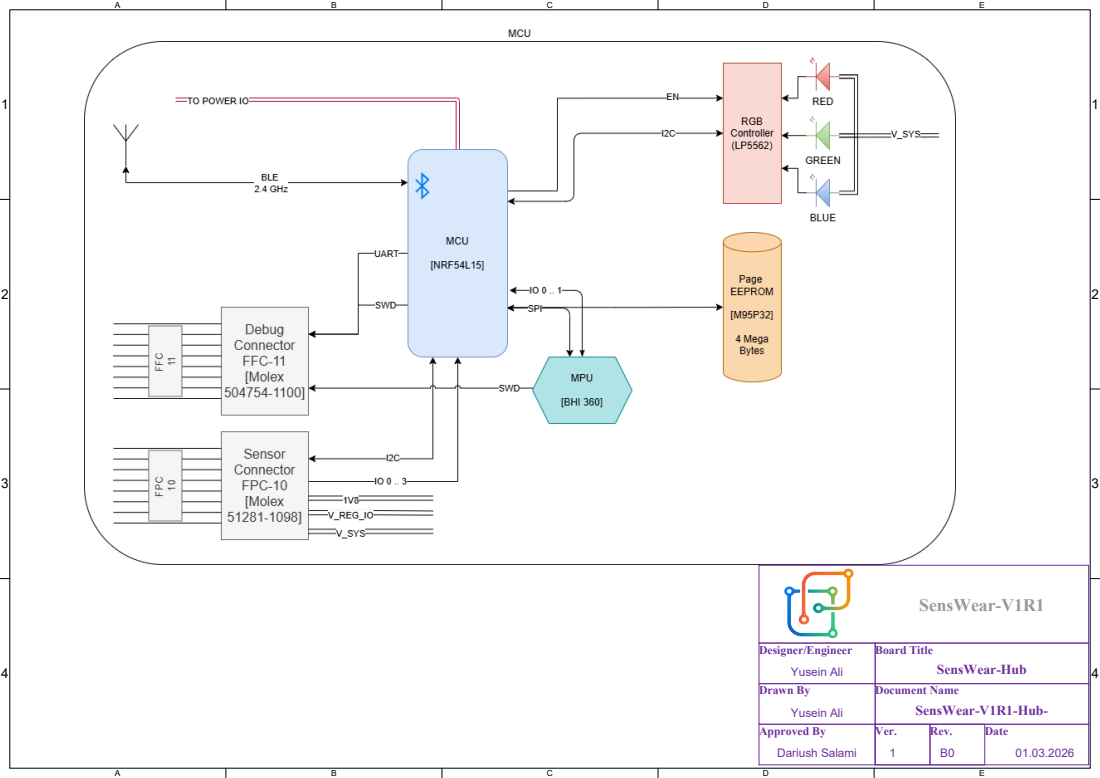
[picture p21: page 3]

Designer/Engineer Yusein Ali | Board Title SensWear-Hub

Drawn By Yusein Ali | Document Name SensWear-V1R1-Hub-

Approved By Dariush Salami | Ver. | B0 | Date 01.03.2026

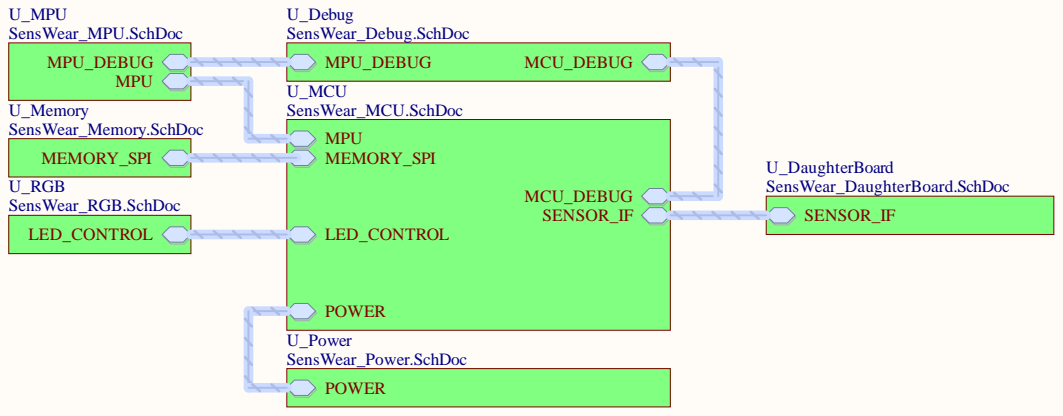
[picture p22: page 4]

SensWear-V1R1

Designer/Engineer Designer/Engineer Yusein Ali Yusein Ali | Board Title Board Title SensWear-Hub SensWear-Hub

Drawn By Yusein Ali | Document Name SensWear-Main.SchDoc SensWear-Main.SchDoc

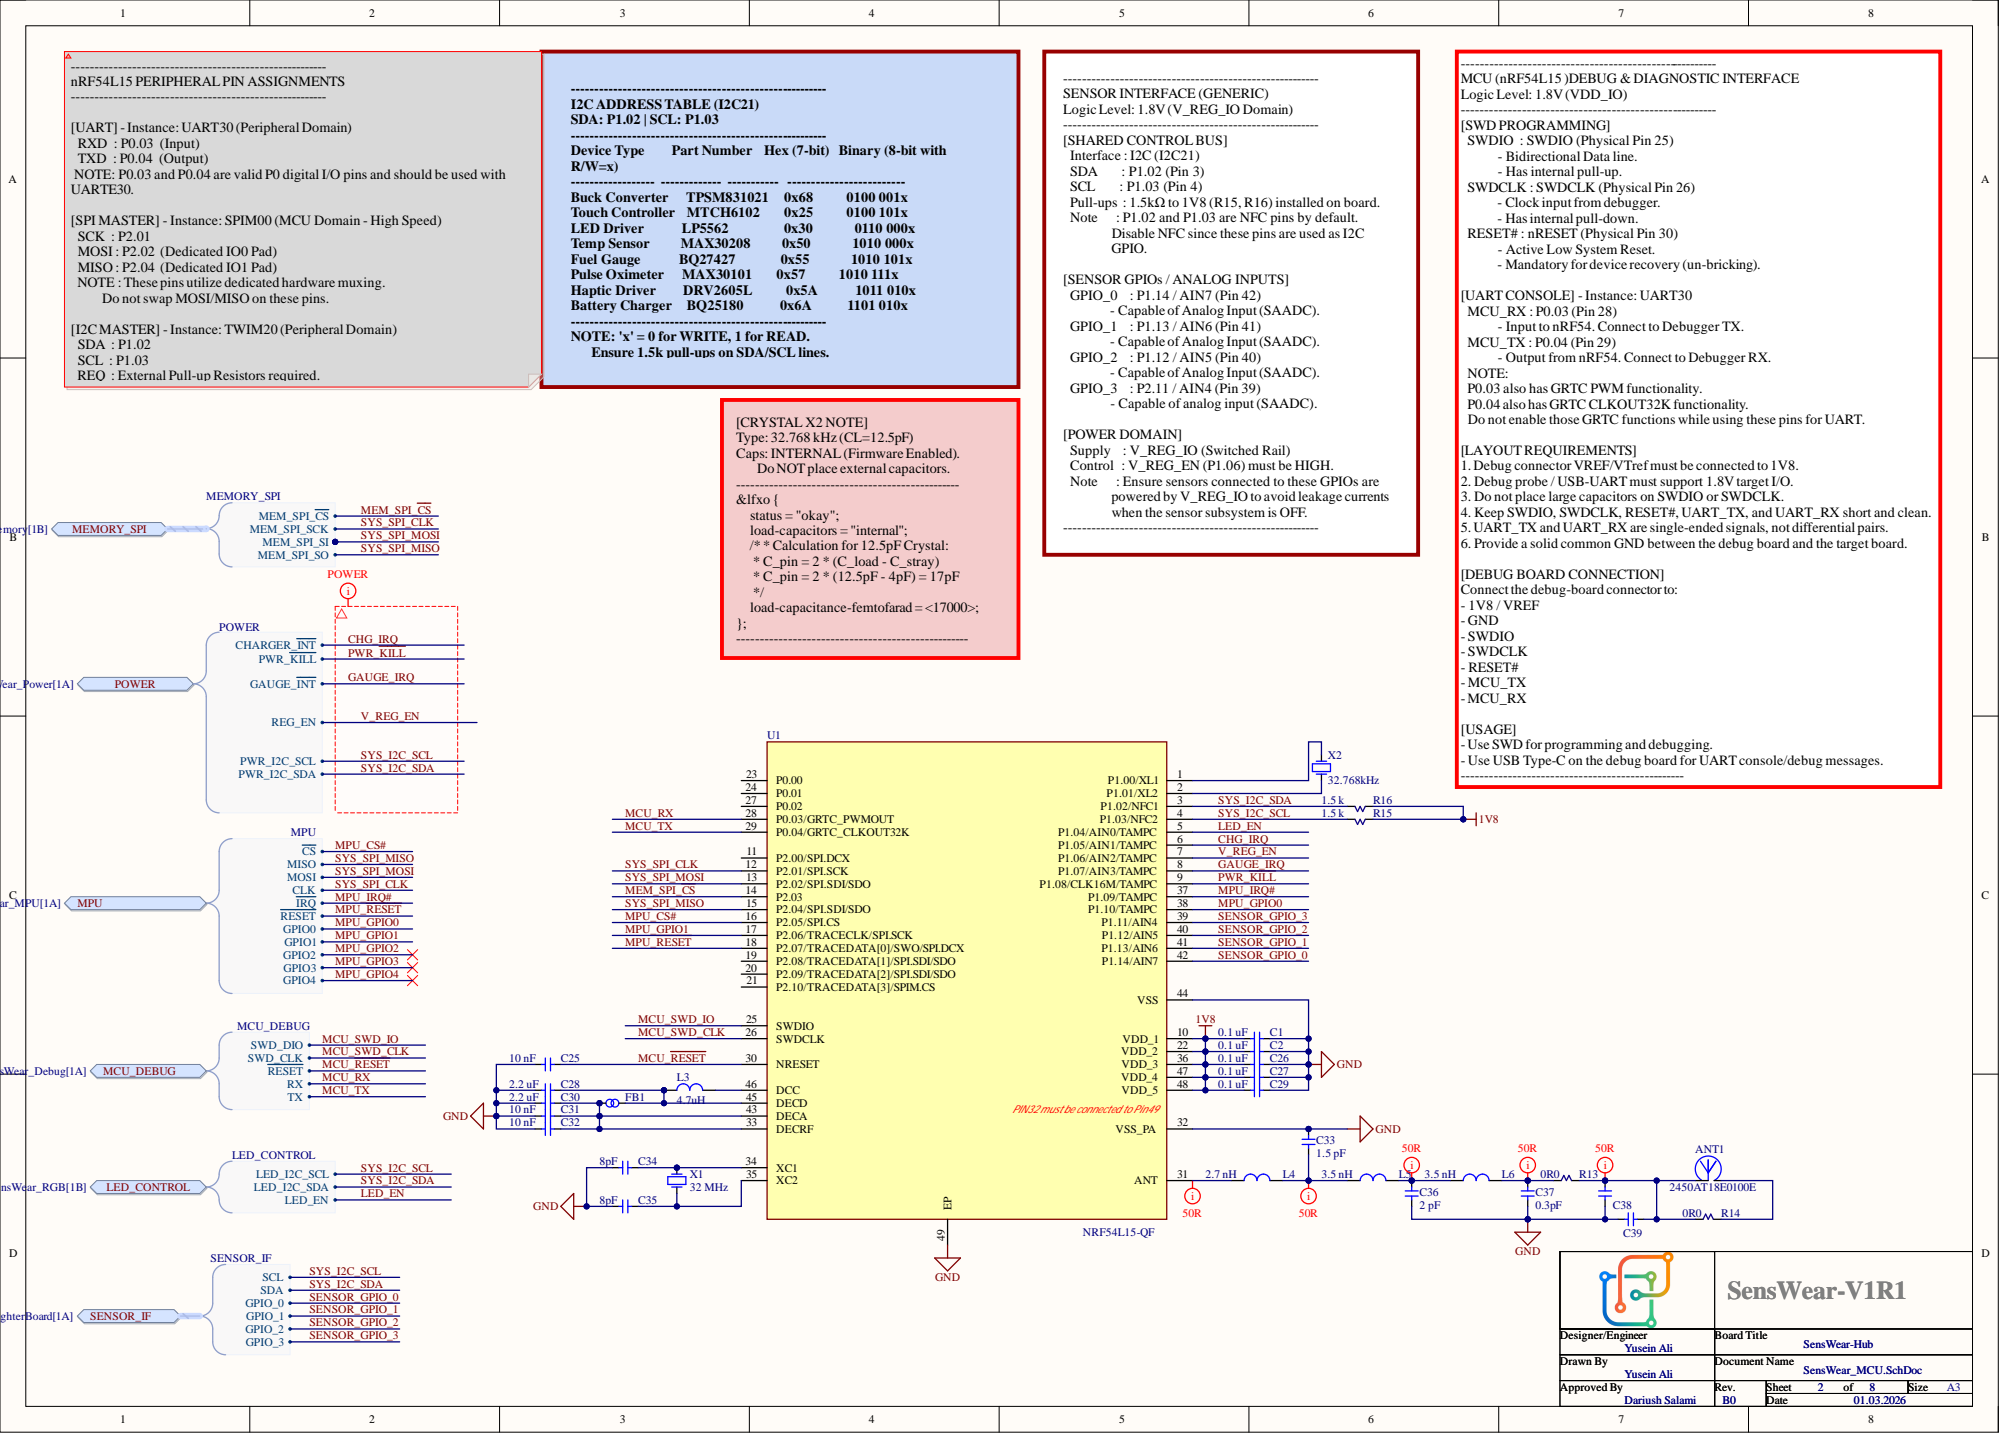
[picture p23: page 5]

[SENSOR GPIOs / ANALOG INPUTS
GPIO_

TAL X2 NOTE]
ps: INTERNAL(Firmware En

ctor VREF/VTref must

SensWear SensWear -V1 -V1 R R 1 1

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

Draw Draw n By n By Yu Yu sei sei n n l l i | ocumen ocumen t t Name Name Sen Sen s s Wear_MCU.Sch Wear_MCU.Sch o o c c

p p pro pro ved ved y y Dari Dari u u s s h Salam h Salam | Rev Rev . . | Shee Shee t t o o f f | Size

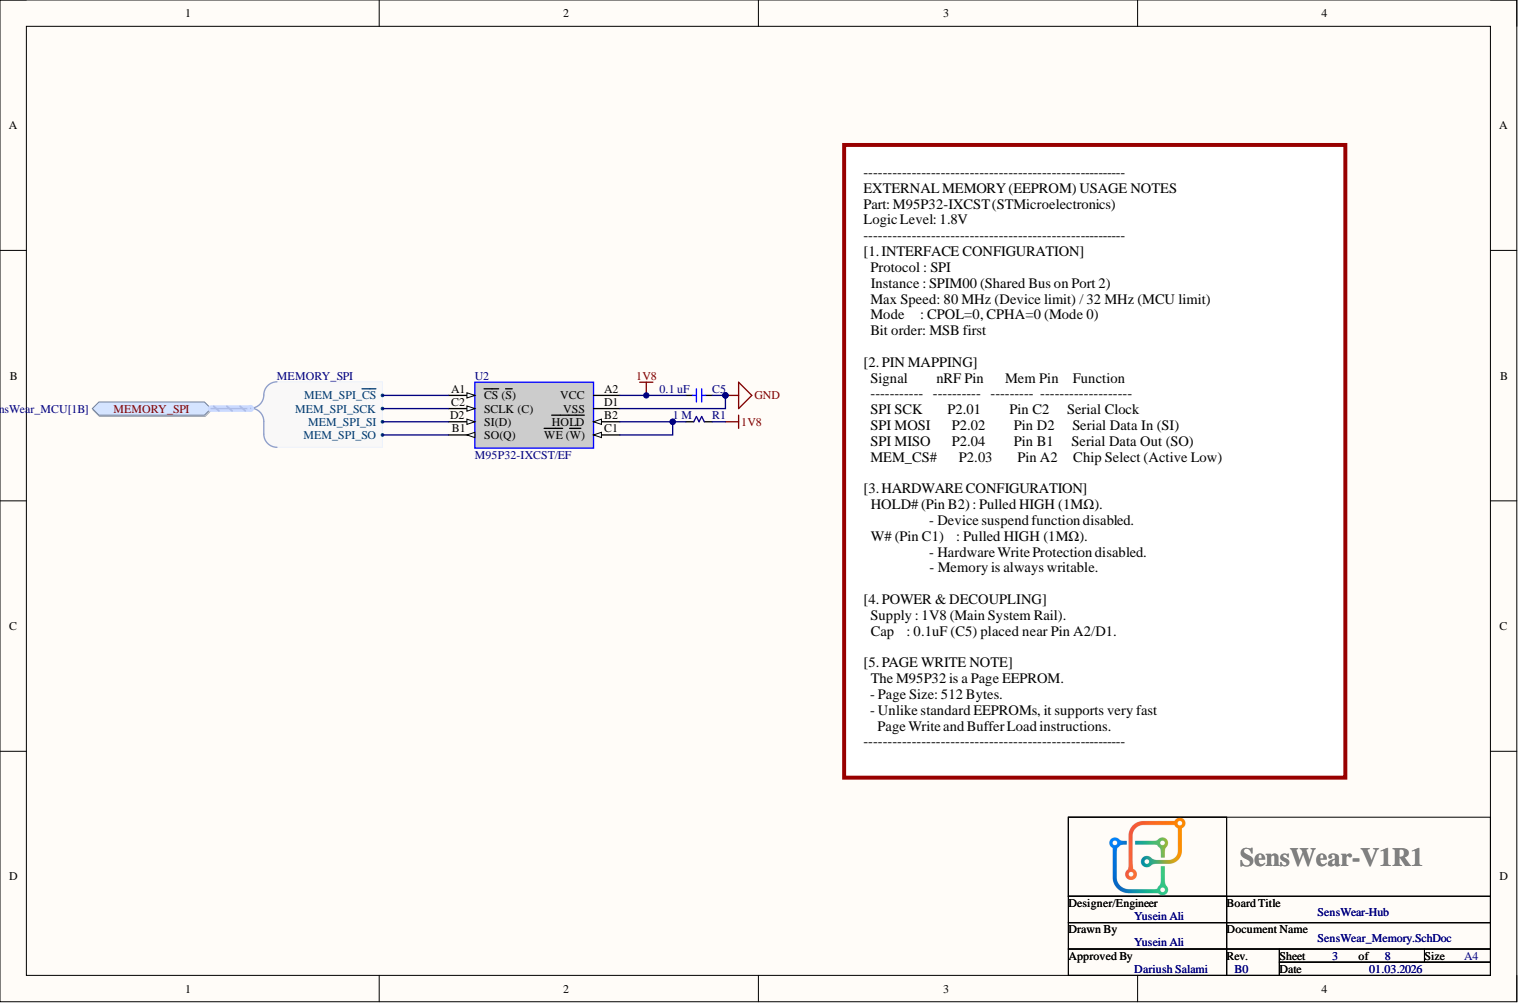
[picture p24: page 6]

erial Clo
erial Data In (SI)
erial Data Out (SO)

SensWear SensWear -V1 -V1 R R 1 1

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

Draw Draw n By n By Yu Yu sei sei n n l l | ocumen ocumen t t Name Name Sen Sen s s Wear_Memory.Sc Wear_Memory.Sc h h o o c c

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

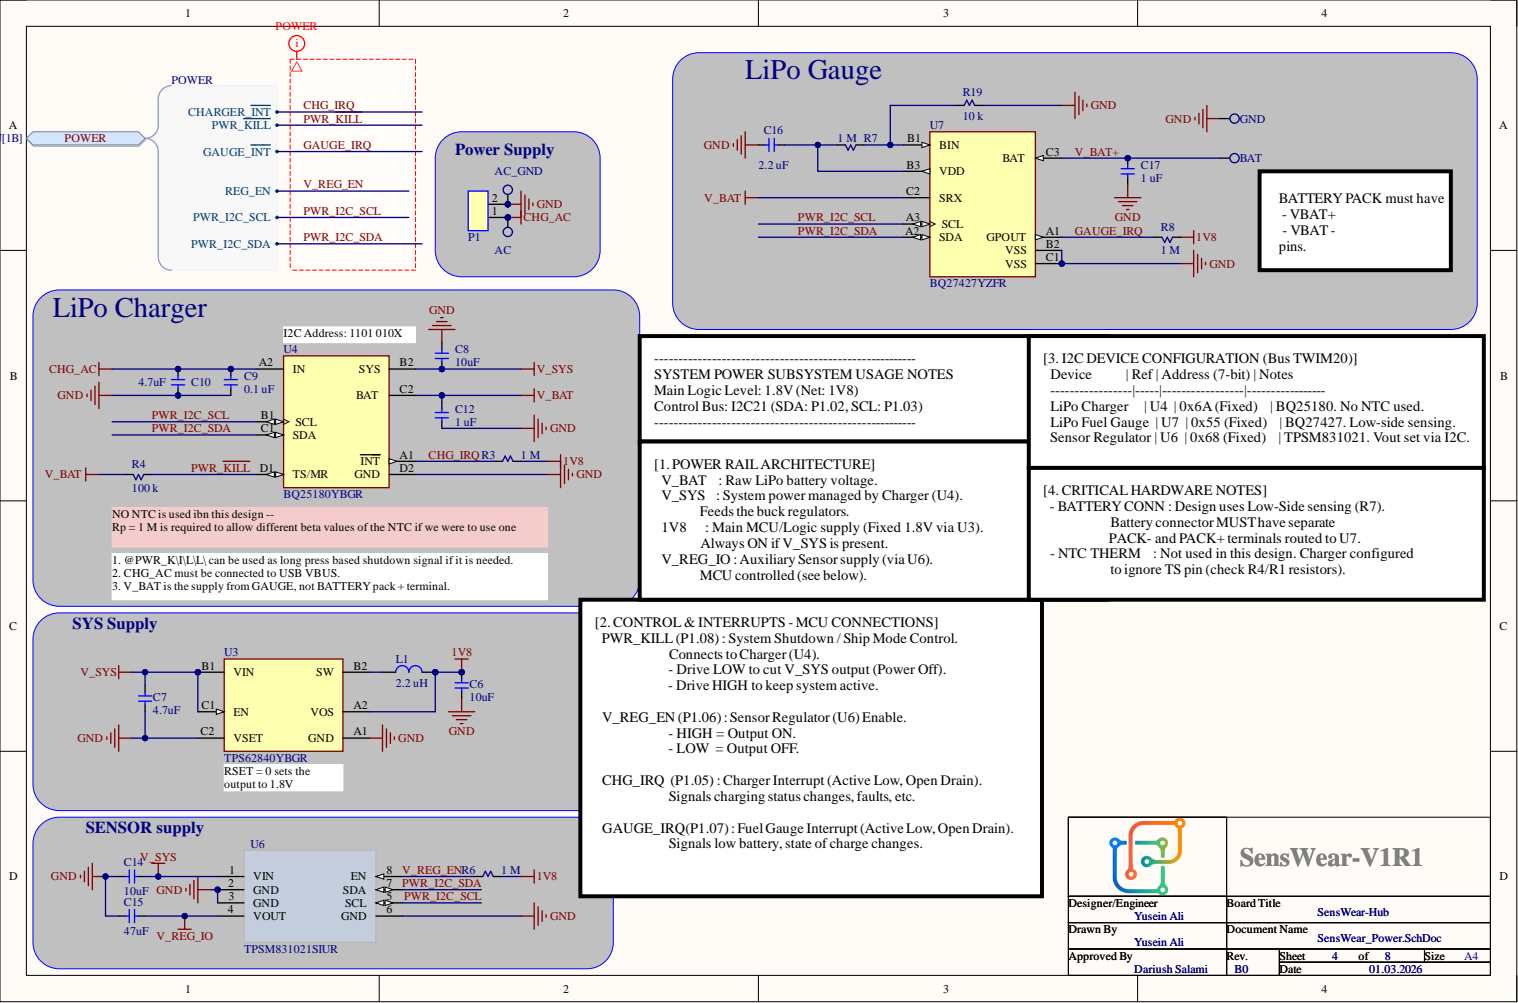
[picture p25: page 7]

-------------------------------------------------------SYSTEM POWER SUBSYSTEM USAGE NOTES Main Logic Level: 1.8V (Net: 1V8) Control Bus: I2C21 (SDA: P1.02, SCL: P1.03) ------------------------------------------------------- | [3. I2C DEVICE CONFIGURATION (Bus TWIM20)] Device -----------------|-----|-----------------|-----------------LiPo Charger | U4 | 0x6A (Fixed) | BQ25180. No NTC used. LiPo Fuel Gauge | U7 | 0x55 (Fixed) | BQ27427. Low-side sensing. Sensor Regulator | U6 | 0x68 (Fixed) | TPSM831021. Vout set via I2C. ------------------------------------------------------- | | Ref | Address (7-bit) | Notes

[1. POWER RAILARCHITECTURE] V_BAT : Raw LiPo battery voltage. V_SYS : System power managed by Charger (U4). Feeds the buck regulators. 1V8 : Main MCU/Logic supply (Fixed 1.8V via U3). Always ON if V_SYS is present. V_REG_IO : Auxiliary Sensor supply (via U6). MCU controlled (see below).

[4. CRITICAL HARDWARE NOTES] - BATTERY CONN : Design uses Low-Side sensing (R7). - NTC THERM : Not used in this design. Charger configured ------------------------------------------------------- | Battery connector MUSThave separate PACK- and PACK+ terminals routed to U7. to ignore TS pin (check R4/R1 resistors).

NO NTC is used ibn this design --
Rp = 1 M is required to allow different beta values of the NTC if we were to use one

1. @PWR_K\I\L\L\ can be used as long press based shutdown signal if it is needed.
2. CHG_AC must be connected to USB VBUS.
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

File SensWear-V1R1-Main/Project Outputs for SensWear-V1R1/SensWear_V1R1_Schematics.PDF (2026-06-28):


SensWear-V1R1

Designer/Engineer Designer/Engineer Yusein Ali Yusein Ali | Board Title Board Title SensWear-RevA SensWear-RevA

Drawn By Yusein Ali | Document Name SensWear-Main.SchDoc SensWear-Main.SchDoc


[SENSOR GPIOs / ANALOG INPUTS
GPIO_

ctor: Ensure VRef (Pin

TAL X2 NOTE]
ps: INTERNAL(Firmware En

SensWear SensWear -V1 -V1 R R 1 1

Des Des g g ner/ ner/ E E g g er er | Board Board T T e Wear-Re Wear-Re v v

Draw n By Yu sei n l i | ocumen t Name Sen s Wear_MCU.Sch Wear_MCU.Sch D o c

p pro ved B y Dari u h Salam | Rev . A | Shee f | Size


erial Clo
erial Data In (SI)
erial Data Out (SO)

SensWear SensWear -V1 -V1 R R 1 1

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

Wear_Memory.Sc Wear_Memory.Sc h h


-------------------------------------------------------SYSTEM POWER SUBSYSTEM USAGE NOTES Main Logic Level: 1.8V (Net: 1V8) Control Bus: TWIM20 (SDA: P1.02, SCL: P1.03) ------------------------------------------------------- | [3. I2C DEVICE CONFIGURATION (Bus TWIM20)] Device -----------------|-----|-----------------|-----------------LiPo Charger | U4 | 0x6A (Fixed) | BQ25180. No NTC used. LiPo Fuel Gauge | U7 | 0x55 (Fixed) | BQ27427. Low-side sensing. Sensor Regulator | U6 | 0x21 (Fixed) | TPSM831021. Vout set via I2C. ------------------------------------------------------- | | Ref | Address (7-bit) | Notes

[1. POWER RAILARCHITECTURE] V_BAT : Raw LiPo battery voltage. V_SYS : System power managed by Charger (U4). Feeds the buck regulators. 1V8 : Main MCU/Logic supply (Fixed 1.8V via U3). Always ON if V_SYS is present. V_REG_IO : Auxiliary Sensor supply (via U6). MCU controlled (see below).

[4. CRITICAL HARDWARE NOTES] - BATTERY CONN : Design uses Low-Side sensing (R7). - NTC THERM : Not used in this design. Charger configured ------------------------------------------------------- | Battery connector MUSThave separate PACK- and PACK+ terminals routed to U7. to ignore TS pin (check R4/R1 resistors).

NO NTC is used ibn this design --
Rp = 1 M is required to allow different beta values of the NTC if we were to use one

1. @PWR_K\I\L\L\ can be used as long press based shutdown signal if it is needed.
2. CHG_AC must be connected to USB VBUS.
3. V_BAT is the supply from GAUGE, not BATTERY pack + terminal.

[2. CONTROL & INTERRUPTS - MCU CONNECTIONS]
PWR_KILL (P2.03) : System Shutdown / Ship Mode Control.

Connects toCharger (U4).
- Drive LOW to cut V_SYS output (Power Off).
- Drive HIGH to keep system active.

CHG_IRQ (P2.09) : Charger Interrupt (Active Low, Open Drain).

Signals charging status changes, faults, etc.

GAUGE_IRQ(P2.08) : Fuel Gauge Interrupt (Active Low, Open Drain).

Signals low battery, state of charge changes.

SensWear-V1R1

Designer/Engineer Designer/Engineer Yusein Ali Yusein Ali | Board Title Board Title SensWear-RevA SensWear-RevA

SensWear_Power.SchDoc


pin HIGH while th

2ms for intern
d 'Host Interfa
d: Burst write firmware RAM

SensWear SensWear -V1 -V1 R R 1 1

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

Wear_MPU.Sch


SensWear SensWear -V1 -V1 R R 1 1

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

Wear_RGB.Sch


ctor: Ensure VRef (Pin

et Core : ARC EM

SensWear SensWear -V1 -V1 R R 1 1

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

Wear_ Wear_ Deb Deb g.S g.S h h


SensWear-V1R1

Designer/Engineer Designer/Engineer Yusein Ali Yusein Ali | Board Title Board Title SensWear-RevA SensWear-RevA

SensWear_TitlePage.SchDoc


SENSOR POWER REGULATOR (U6)
Part: TPSM831021SIUR
[HARDWARE CONFIGURATION]
Input : V_SYS (System Voltage)
Output : V_REG_IO (Sensor Logic Supply)
I2C Addr : 0x21 (7-bit)
(Factory programmed, VOUTconfigurable)

SENSOR INTERFACE (GENERIC)
Logic Level: 1.8V(V_REG_IO Domain)
[SHARED CONTROLBUS]
Interface : I2C (TWIM20)
Pull-ups : 1.5kΩ to 1V8 (R15, R16) installed on board.
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

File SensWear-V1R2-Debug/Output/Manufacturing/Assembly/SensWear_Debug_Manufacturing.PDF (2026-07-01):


Line # 123456789 | C51 | 4.7uF

B50, B51, B52 | B3U-1000P | Quantity 361
Designator | Comment

View from Top side (Scale 5:2)

C69, C70 | 15pF
CABLE50 | 0150310411
D50 | MBR140SFT1G
D51, D52, D53 | LTST-C155KGJRKT
FB50 | BLM15AG601SN1D

10 | L50 | 2.2 uH
11 | L51 | 3.3µH

13 | R54 | 1 M
14 | R55 | 267kΩ
15 | R56, R58 | 27Ω
16 | R57 | 33R
17 | R59, R62, R63, R74, R75, R76, R77, R78, R79 | 1 k

View from Bottom side (Scale 5:2)

20 | R68, R69, R70, R71, R72, R73 | 620 R
21 | SWD_RP50, UART_RP50 | SM03B-SRSS-TB(LF)(SN)

29 | USB50 | DX07S024JJ3R1300
30 | X50 | 12MHz

Designer/Engineer Yusein Ali | Board Title SensWear-Debug

Drawn By Yusein Ali | Document Name SensWear-V1R2-Debug-

Approved By Dariush Salami | Ver. 1.0 | Rev. A0 | Date 20.06.2026

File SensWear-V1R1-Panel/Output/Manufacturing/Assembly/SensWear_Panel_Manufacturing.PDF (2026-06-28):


View from Top side (Scale 5:1)

View from Bottom side (Scale 5:1)

Designer/Engineer =Engineer | Board Title =BoardName

Drawn By =DrawnBy | Document Name SensWear_SensorPanel_V1R1.PCB

Approved By =ApprovedBy | Ver. =Versi | Rev. | Date


All stifnners have the same dimension shown in Detail A

Total thickness must be 0.3 mm

Designer/Engineer =Engineer | Board Title =BoardName

Drawn By =DrawnBy | Document Name SensWear_SensorPanel_V1R1.PCB

Approved By =ApprovedBy | Ver. =Versi | Rev. | Date

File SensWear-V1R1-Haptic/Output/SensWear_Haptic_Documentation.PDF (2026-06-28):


Name | File | Description

Main | SensWear_Haptic | Controller IC and connectors

Revision | Date | Description
A0 | May 2025 | Initial validation design on rigid PCB
B0 | March 2026 | Flexible PCB manufacturing updates: BGA package DRV2605 is replaced with SOP package

Designer/Engineer Yusein Ali | Board Title SensWear-Haptic

Drawn By Yusein Ali | Document Name SensWear-V1R1-

Approved By Dariush Salami | Ver. | Rev. B0 | Date 01.03.2026


SensWear SensWear -V1 -V1 R R 1 1

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

p p pro pro ved ved y y Dari Dari u u s s h Salam h Salam i i | Rev Rev . . B0 B0 | Shee Shee t t o o f f | Size


View from Top side (Scale 4:1)

View from Bottom side (Scale 4:1)

Line # | Designator | Comment | Quantity
1 | C40, C43, C44 | 4.7uF | 3
2 | C41 | 1 uF | 1
3 | C42 | 0.47 uF | 1
4 | CONN40 | NC | 1
5 | M40 | G0832012 | 1
6 | P40 | 51281-1098 | 1
7 | U40 | DRV2605LDGSR | 1

Designer/Engineer Yusein Ali | Board Title SensWear-Haptic

Drawn By Yusein Ali | Document Name SensWear-V1R1-Haptic-

Approved By Dariush Salami | Ver. | Rev. B0 | Date 01.03.2026

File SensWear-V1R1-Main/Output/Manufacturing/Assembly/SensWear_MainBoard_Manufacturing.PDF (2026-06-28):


View from Top side (Scale 5:1)

View from Bottom side (Scale 5:1)

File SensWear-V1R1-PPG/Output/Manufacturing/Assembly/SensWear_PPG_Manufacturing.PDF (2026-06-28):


View from Top side (Scale 4:1)

View from Bottom side (Scale 4:1)

Line # | Designator | Comment | Quantity
1 | C50, C53, C54 | 4.7uF | 3
2 | C51, C52 | 10uF | 2
3 | CONN50 | NC | 1
4 | P50 | 51281-1098 | 1
5 | R50 | 1.5 k | 1
6 | U50 | MAX30101EFD+T | 1

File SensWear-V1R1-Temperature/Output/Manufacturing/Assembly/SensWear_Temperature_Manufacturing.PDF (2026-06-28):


View from Top side (Scale 4:1)

View from Bottom side (Scale 4:1)

Line # | Designator | Comment | Quantity
1 | C60 | 0.1 uF | 1
2 | CONN60 | NC | 1
3 | U60 | MAX30208CLB+T | 1

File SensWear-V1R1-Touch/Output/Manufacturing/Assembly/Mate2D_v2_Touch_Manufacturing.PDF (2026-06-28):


View from Top side (Scale 4:1)

View from Bottom side (Scale 4:1)

Line # | Designator | Comment | Quantity
1 | C70 | 0.47 uF | 1
2 | CONN70 | NC | 1
3 | R70, R71, R72 | 1.5 k | 3
4 | Touch | NC | 1
5 | U70 | MTCH6102-I/MV | 1

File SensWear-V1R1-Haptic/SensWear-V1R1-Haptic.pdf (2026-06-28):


Designe Designe r/En r/En g g in in e e e e r r | Boa Boa rd rd Titl Titl e e

Dr Dr awn awn B B y y | Document Document N N ame ame OpenRing_Haptic OpenRing_Haptic . . S S c c hD hD o o c c

Approved Approved B B y y | R R e e v. v. | She She et et 1 1 o o f f 1 1 | Siz Siz e e A4 A4

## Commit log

2026-07-01 Debug output files
    [Bill of Materials-SensWear-V1R2-Debug.xlsx, Pick Place for SensWear-V1R2-Debug.csv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]
2026-07-01 manuf files regenerated and different boms created
    [Bill of Materials-SensWear-V1R2-Debug-JLCPCB Assembly Order.xls, Bill of Materials-SensWear-V1R2-Debug.xlsx, Pick Place for SensWear-V1R2-Debug.csv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]
